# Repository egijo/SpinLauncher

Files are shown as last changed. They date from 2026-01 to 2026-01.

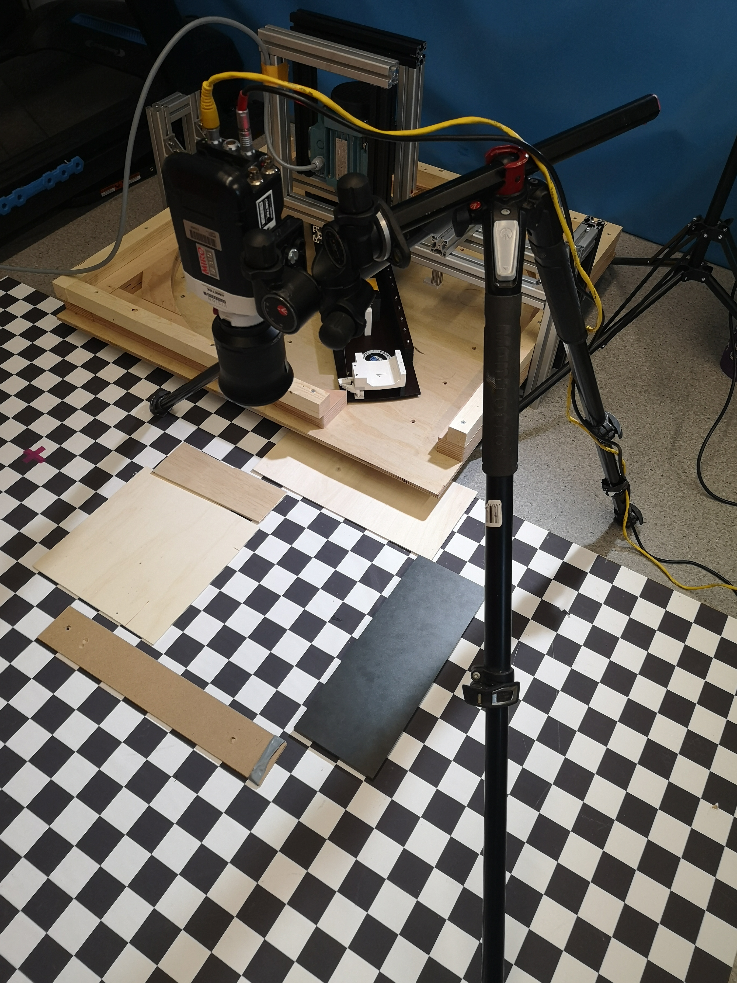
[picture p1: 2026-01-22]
pictures/Messsetup/V1/IMG_20260114_160319.jpg

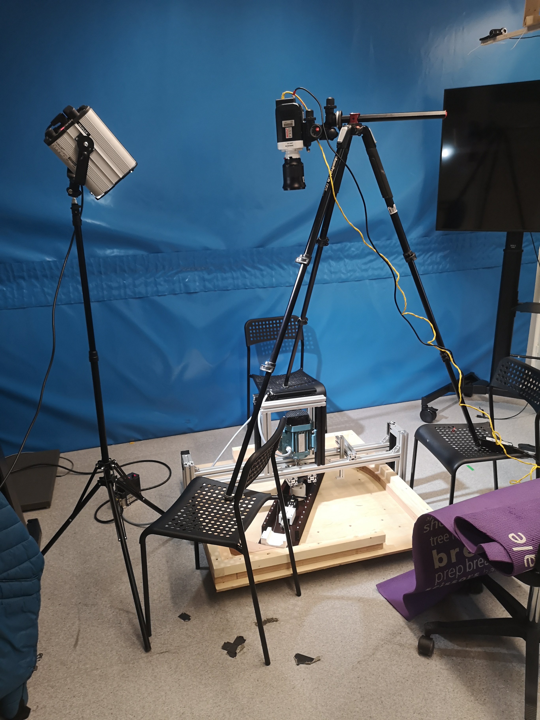
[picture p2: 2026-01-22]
pictures/Messsetup/V1/IMG_20260108_142438.jpg

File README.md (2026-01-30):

# SpinLauncher

## Project Group
- Mara Sandner
- Ruven Overberg
- Jonas Egitz

## Project Overview
The SpinLauncher is a mechanical puck launching system designed to accelerate an ice hockey puck using centrifugal force. A rotating arm generates controlled launch velocities, allowing different puck speeds to be set reproducibly. In addition to linear speed control, the system enables the generation of puck spin, which is relevant for realistic shot simulation.

The primary goal of the SpinLauncher is to produce repeatable and well-defined hockey shots. The system was developed as an extension and improvement of the shooting device used in the master’s thesis “Hockey Pro”, which aimed to generate reproducible shots for a camera-based ice hockey shooting training system.

The SpinLauncher project was carried out as a student project within the Master’s program (MST) during the Winter Semester 2025/2026.

## System Concept & Principle
The core mechanical concept of the SpinLauncher is a horizontally rotating arm driven by an electric motor. Two standard ice hockey pucks are mounted at opposite ends of the arm. This symmetric configuration ensures dynamic balance during rotation, significantly reducing vibrations and mechanical stress on the system.

During operation, both pucks are accelerated simultaneously and experience identical centrifugal forces. The system is designed for bidirectional release, meaning that the mechanical release principle is implemented on both sides of the rotating arm. In experimental operation, however, only one puck is used for measurement, while the second puck is safely intercepted. This approach preserves balance.

By adjusting the rotational speed of the arm, the launch velocity of the puck can be precisely controlled. The combination of symmetric mass distribution and controlled release enables reproducible shot conditions and stable system behavior.

## Hardware Setup
The SpinLauncher hardware consists of a mechanically simple but dynamically balanced rotating system. The central component is a rigid wooden arm with a total diameter of approximately 80 cm, mounted horizontally and driven by an electric asynchronous motor. The geometry and dimensions of the rotating arm are defined in the CAD model [`/drawings`](./drawings).

Two standard ice hockey pucks are mounted at opposite ends of the rotating arm. This symmetric mass distribution ensures dynamic balance during operation and significantly reduces vibrations at higher rotational speeds. Each puck is inserted into a release mechanism. It is designed to imediately release the puck when it is being triggered. The servo mounted on the rotor is connected to the trigger through a wire. If the servo moves, it will pull the trigger of the release mechanism. This will release the puck as an outcome and the puck will be pressed against the wall because of the centrifugal forces. The next time the rotor will pass the puck outlet, the puck will fly through the outlet. The puck holders and integrated release mechanisms are defined in
[`/releaseMechanism`](./releaseMechanism). and the corresponding part files in the same directory.

The electronic components required for motor control and sensor feedback are documented in the [`/Electronic`](Electronic) directory. This folder contains the complete circuit schematic, including the motor drive, power supply, and the Hall effect sensor used for rotational speed measurement.

The rotating arm is connected to the motor shaft via a torque coupling, which ensures reliable torque transmission while maintaining axial alignment. All rotating components are mounted on a rigid frame structure made out ot ITEMs that supports the motor and ensures a stable horizontal rotation axis. The frame design, including mounting points for the motor and safety elements, is defined in [`/drawings`](./drawings).

## Control & Software
The SpinLauncher is controlled via a software-based speed control system that enables precise and reproducible adjustment of the launcher’s rotational velocity. The rotational speed of the arm is measured in real time using a Hall effect sensor, which detects the rotation of the motor shaft and provides feedback in the form of pulses. From these pulses, the system continuously calculates the current rotational speed in revolutions per minute (RPM).

The measured RPM is used to monitor the acceleration process and to verify that the predefined target speed has been reached. This feedback mechanism allows reliable speed setting and ensures that launches are performed only under well-defined conditions.

All control-related code is located in the [`/SpinlaunchController`](SpinlaunchController) directory of this repository.

In addition to the embedded control logic, a web-based control interface is implemented directly on the controller. The system hosts a lightweight web server that allows the user to:
- set target RPM values,
- set of release angle
- monitor the current rotational speed,
- manually trigger the puck release.

The release can be initiated via the web interface once the system has reached the predefined target RPM and angular position. This ensures that the puck is released only when both speed and orientation conditions are satisfied, improving repeatability and experimental control.

The modular structure of the control software allows easy modification of speed thresholds, angular conditions, and trigger logic. This design enables future extensions, such as automated release criteria, closed-loop speed control, or integration of additional sensor feedback.

## Experimental Setup & Test Procedure

### Experimental Setup

All experiments were conducted using a controlled laboratory setup designed to ensure reproducible launch and measurement conditions. The SpinLauncher was placed on the floor, and all measurements were performed under identical mechanical, camera, and lighting conditions.

High-speed recordings were acquired using a visually triggered camera system operating in an image-based auto-trigger mode. Image sequences were recorded before and after puck launch to capture the complete release event. The camera was positioned perpendicular to the puck trajectory, facing a calibrated checkerboard plane.

The camera configuration was identical for all experiments and is summarized below:

- **Frame rate:** 3200 fps  
- **Exposure time (shutter speed):** 310 µs  
- **Sensor resolution:** 1280 × 800 pixels  
- **Bit depth:** 12 bit  
- **Lens:** Fixed-focus lens, focal length 25 mm  
- **Distance between camera lens and checkerboard plane:** 52.5 cm  
- **Trigger mode:** Image-based auto-triggering based on grayscale intensity changes  
- **Recording duration:** approx. 0.09 s pre-trigger and 0.55 s post-trigger  

Images of the complete experimental setup, including camera placement and launcher orientation, are provided in the [`/pictures`](./pictures) directory.

### Test Procedure

The SpinLauncher was tested at multiple predefined target velocities. For each target speed, the launcher was accelerated to the corresponding rotational speed before the puck release was manually triggered.

The following test conditions were investigated:

- **25 km/h (≈ 166 RPM):** 11 repetitions  
- **45 km/h (≈ 299 RPM):** 11 repetitions  
- **55 km/h (≈ 365 RPM):** 2 repetitions  

The number of repetitions at 55 km/h was limited due to **mechanical failure of the system**, which resulted in damage to the launcher and prevented further testing at this speed.

All measurement data, including raw results and processed values, are stored in the [`/Measurements/V2`](./Measurements/V2) directory. This folder contains:
- recorded measurement data,
- analysis scripts,
- and the corresponding Excel files that logged the test run. 

The software and data provided in this repository allow full traceability of the experimental procedure and results presented in the paper and presentation.

## Data & Analysis

The recorded measurement data were processed and analyzed to evaluate the launch velocity and repeatability of the SpinLauncher. All raw data and processed results are stored in the [`/Measurements/V2`](./Measurements/V2) directory.

Launch velocities were determined based on image sequences recorded with the high-speed camera. The puck position was extracted frame by frame using a **custom Python analysis script**, and the displacement over time was used to calculate the translational velocity after release. Only frames in which the puck had fully disengaged from the launcher were considered for evaluation.

High-speed video recordings were used to estimate the puck velocity over a planar checkerboard pattern. The camera was intrinsically calibrated using 23 checkerboard images (4×5 inner corners, 35×35mm square size), and the resulting calibration parameters were applied to undistort all videos. The puck was tracked frame-wise using a CSRT tracker, while the background checkerboard (5×5cm) provided a spatial reference for converting pixel coordinates to real-world distances. From the tracked positions, distance–time data were extracted, stored in CSV format, and used to compute velocities and generate distance–time and scatter plots.

For each target speed, multiple repetitions were analyzed to assess repeatability. Mean values and variations of the measured launch velocities were calculated and used to compare the achieved performance across different operating points. The resulting values form the basis for the plots and tables presented in the presentation and paper.

The Python scripts used for data processing is provided in the [`/Measurements/V2`](./Measurements/V2) directory. All analysis steps are documented and can be reproduced or extended by future users.

## Results Summary

The SpinLauncher demonstrated reliable and reproducible performance across the tested velocity range. For target speeds of **25 km/h** and **45 km/h**, the system achieved stable operation with consistent launch conditions over **11 repeated trials** each. The measured launch velocities showed low variation between repetitions, indicating good repeatability of the centrifugal acceleration and release mechanism.

At higher target speeds, the system approached its mechanical limits. Tests at **55 km/h** were successfully performed for **two repetitions**, confirming the feasibility of higher launch velocities in principle. However, subsequent testing at this speed was discontinued due to mechanical failure of the launcher, which resulted in damage to the system. This failure highlights the increasing structural and dynamic loads acting on the rotating components at elevated rotational speeds. In addition, the response time of the release mechanism was insufficient at higher rotational speeds, leading to delayed puck disengagement and contributing to the observed mechanical failure.

All raw and processed measurement data supporting these results are stored in the [`/Measurements/V2`](./Measurements/V2) directory. This folder contains the complete dataset used for analysis, including measurement files, evaluation scripts, and plots.

Overall, the results confirm that the SpinLauncher is well suited for generating reproducible puck launches within a moderate speed range. The experimental data further provide valuable insight into the mechanical limitations of the current design and define clear boundaries for safe and reliable operation.

## Limitations and Future Work

The current SpinLauncher design exhibits several limitations that became apparent during high-speed testing and provide clear directions for future improvements.

One key limitation is the performance of the release mechanism. At elevated rotational speeds, the response time of the current mechanism is insufficient, leading to delayed puck disengagement. Future work should focus on improving the release dynamics to ensure reliable operation at higher RPMs. In particular, the use of a linear pin actuator with sufficient pulling force should be considered as an alternative to the currently used servo-based solution.

Another limitation concerns the structural stiffness of the rotating arm. At higher rotational speeds, the arm exhibited noticeable deflection, causing parts of the rotating assembly to come into contact with surrounding components. This indicates that the arm stiffness is insufficient for operation at higher loads. Future iterations should therefore include structural reinforcement of the rotating arm or the use of stiffer materials.

A further limitation is the limited control and quantification of puck spin. While spin is generated implicitly by the launcher, it is neither independently adjustable nor directly measured. A potential approach to influence puck spin is to vary the launching angle, which may allow controlled manipulation of rotational behavior. In principle, the high-speed camera recordings acquired during the experiments provide sufficient data to extract and analyze puck spin. However, no dedicated analysis or systematic investigation of spin effects has been conducted so far.

Safety is another important aspect that requires improvement. In the current setup, the second puck mounted on the rotating arm remains in motion after the primary puck is released. As a concrete future improvement, the unused puck should be intercepted immediately at the launcher exit using a dedicated catching or deflection mechanism. This would significantly reduce the risk associated with uncontrolled puck motion and improve the overall safety of the system.

Addressing these limitations is expected to increase the maximum achievable launch speed while improving reliability, experimental control, and operational safety.

## Further Documentation
Paper:

Notion: https://www.notion.so/mci-medtech/Hockey-PRO-28091a52c19480998451c0e8b286c635

final Presentation: [`Presentation`](Documentation)

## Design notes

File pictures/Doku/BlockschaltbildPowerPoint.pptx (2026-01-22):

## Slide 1

Voltage Regulator

Battery

µC

Servo

Hall Effect Sensor

Webserver

Logic

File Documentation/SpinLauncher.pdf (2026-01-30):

1

# SpinLauncher

Jonas, Ruven, Mara

2

# Background & Project Goal

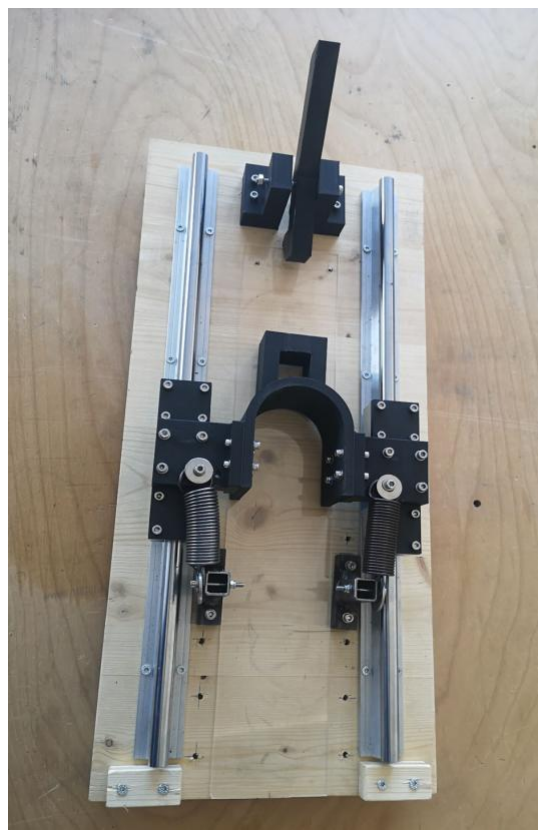
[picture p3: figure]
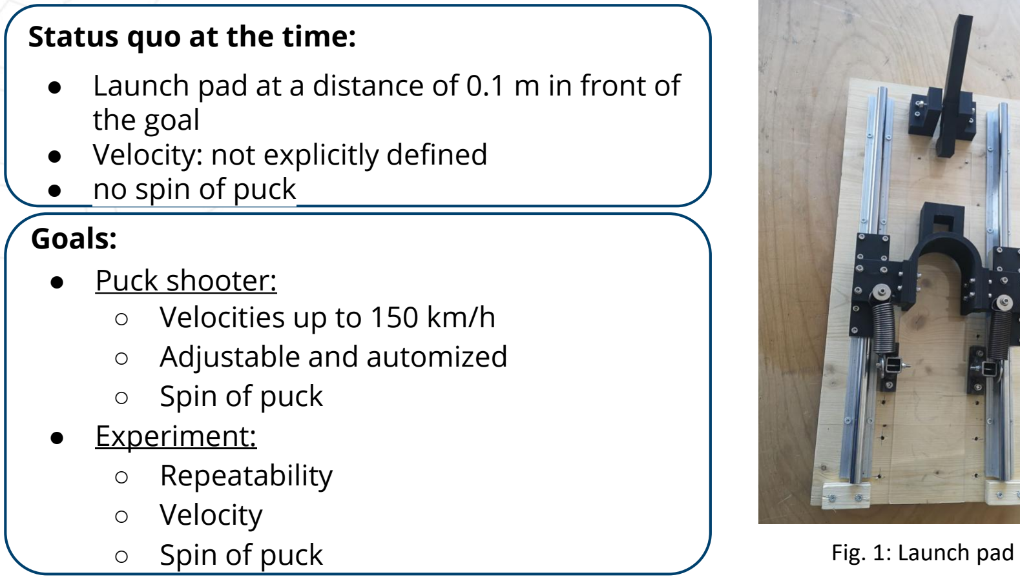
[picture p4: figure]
Status quo at the time:; the goal ● Velocity: not explicitly defined ● no spin of puck; Goals: ● Puck shooter: ○ Velocities up to 150 km/h ○ Adjustable and automized ○ Spin of puck ● Experiment: ○ Repeatability ○ Velocity; ○ Spin of puck; Fig. 1: Launch pad

- Launch pad at a distance of 0.1 m in front of

3

# Research Question

The aim of this project was to

### 1. develop a new launching system and 2. How consistent and stable is the hockey puck behaviour produced

by the new developed puck launching system (SpinLauncher), specifically regarding trajectory accuracy, velocity and spin?

4

# Decision Matrix

| Catapult | Spin Launch | Springs | 2-3 Wheels | Railgun | Free Fall - Gravity | 10 Wheels
Complexity | 5 | 4 | 4 | 5 | 10 | 1 | 7
Spin | 3 | 3 | 10 | 1 | 8 | 7 | 1
Velocity | 5 | 1 | 9 | 4 | 1 | 7 | 3
Size | 7 | 5 | 2 | 2 | 5 | 10 | 4
Complexity Release Mechanism | 2 | 4 | 2 | 1 | 3 | 1 | 1
Repeatability | 2 | 1 | 1 | 4 | 1 | 4 | 3
Feasibility | 6 | 3 | 2 | 3 | 10 | 2 | 4
Sum | 30 | 21 | 30 | 20 | 38 | 32 | 23

5

# SpinLauncher - Block diagram

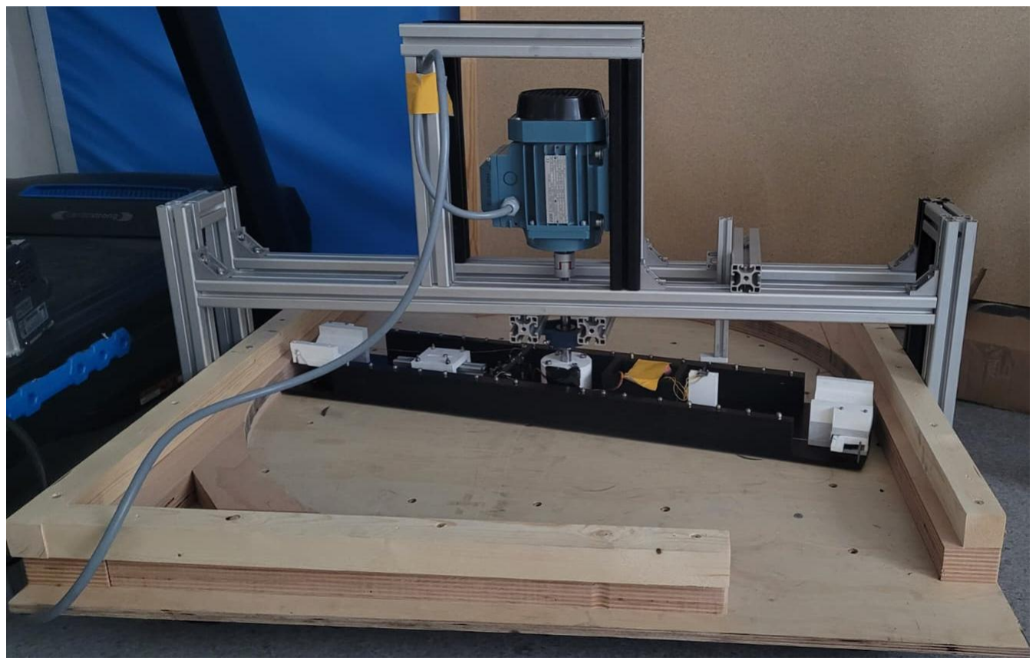
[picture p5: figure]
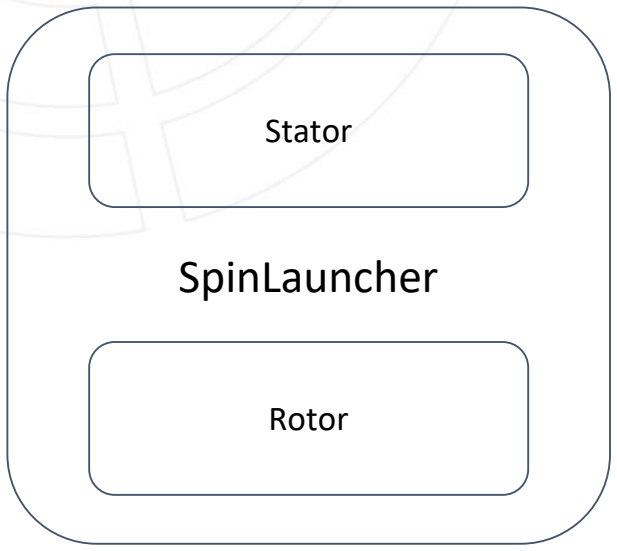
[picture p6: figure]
SpinLauncher; Stator; Rotor

Fig. 2: SpinLauncher block diagram | Fig. 3 : SpinLauncher

6

# - ITEM frame

# - wood boundaries

# - Bearings

# - 3 Phase asynchronous motor

# - 1 Phase AC frequency converter

# SpinLauncher - Stator

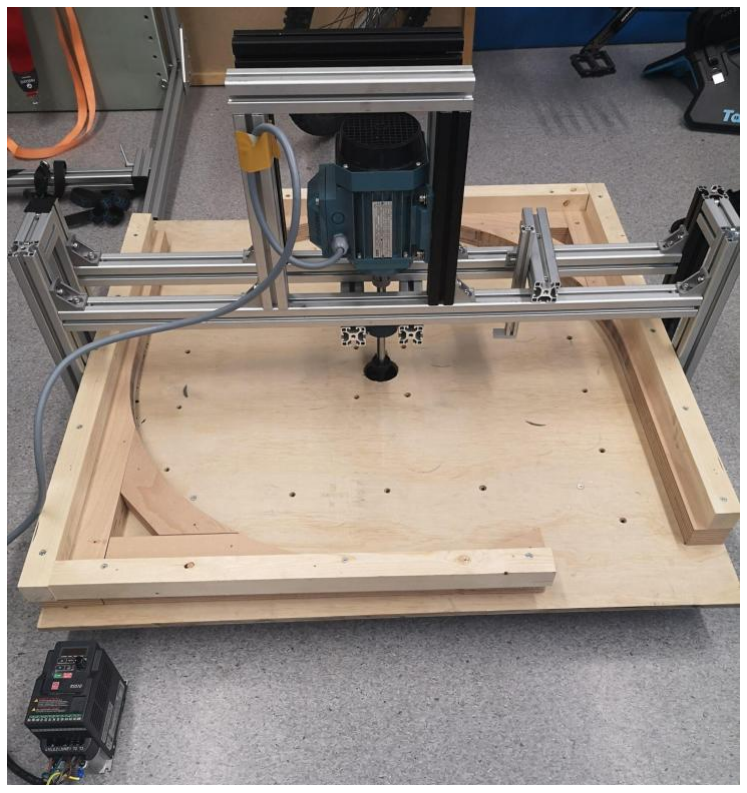
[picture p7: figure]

Fig. 4: SpinLauncher - Stator

7

## - wood construction

## - 2x release mechanism

## - Counterweight

## - Servo motor

- µC

## - Battery

## - Hall effect sensor

# SpinLauncher - Rotor

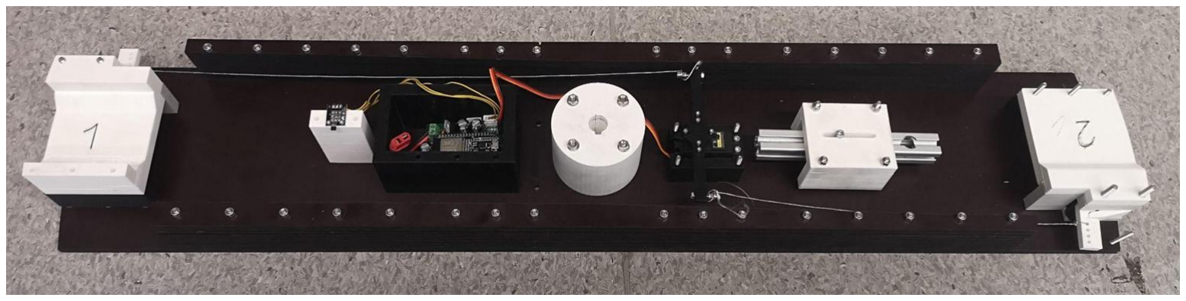
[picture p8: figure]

Fig. 5: SpinLauncher - Rotor

8

# Electronic Block Diagram

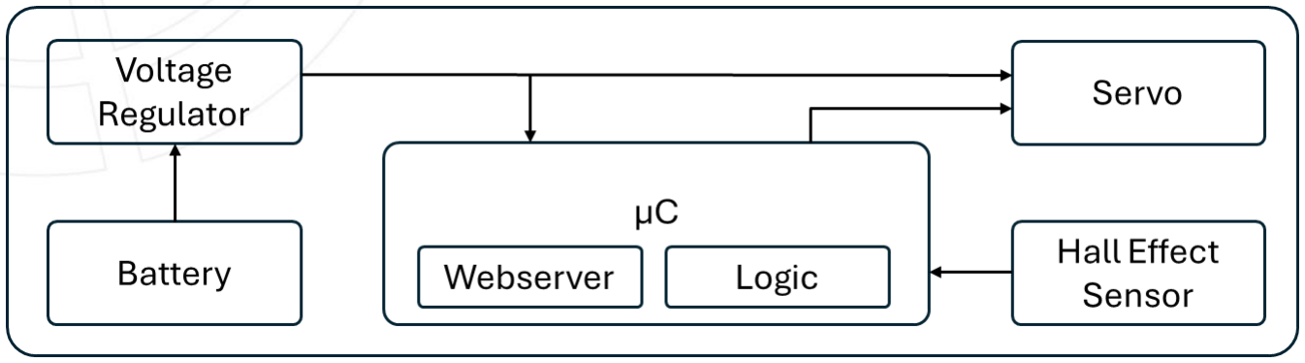
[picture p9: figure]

Fig. 6: Block diagram of electronic on Rotor

# Release Mechanism Design

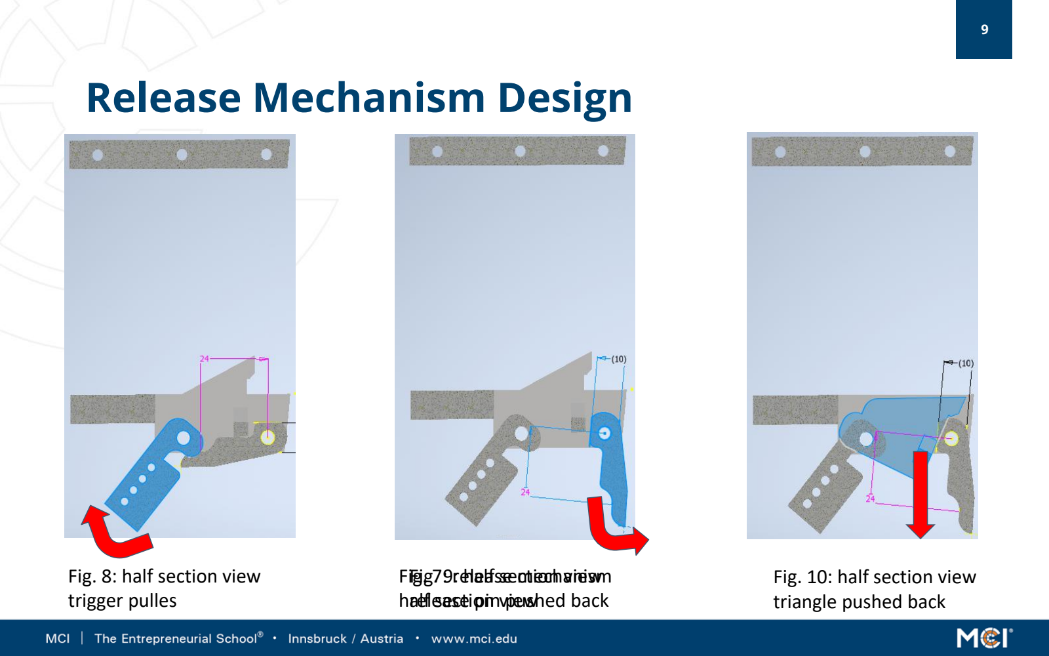
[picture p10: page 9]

9

Fig. 7: release mechanism
half section view

Fig. 8: half section view
trigger pulles

Fig. 9: half section view
release pin pushed back

Fig. 10: half section view triangle pushed back

# Experimental Setup Schematic

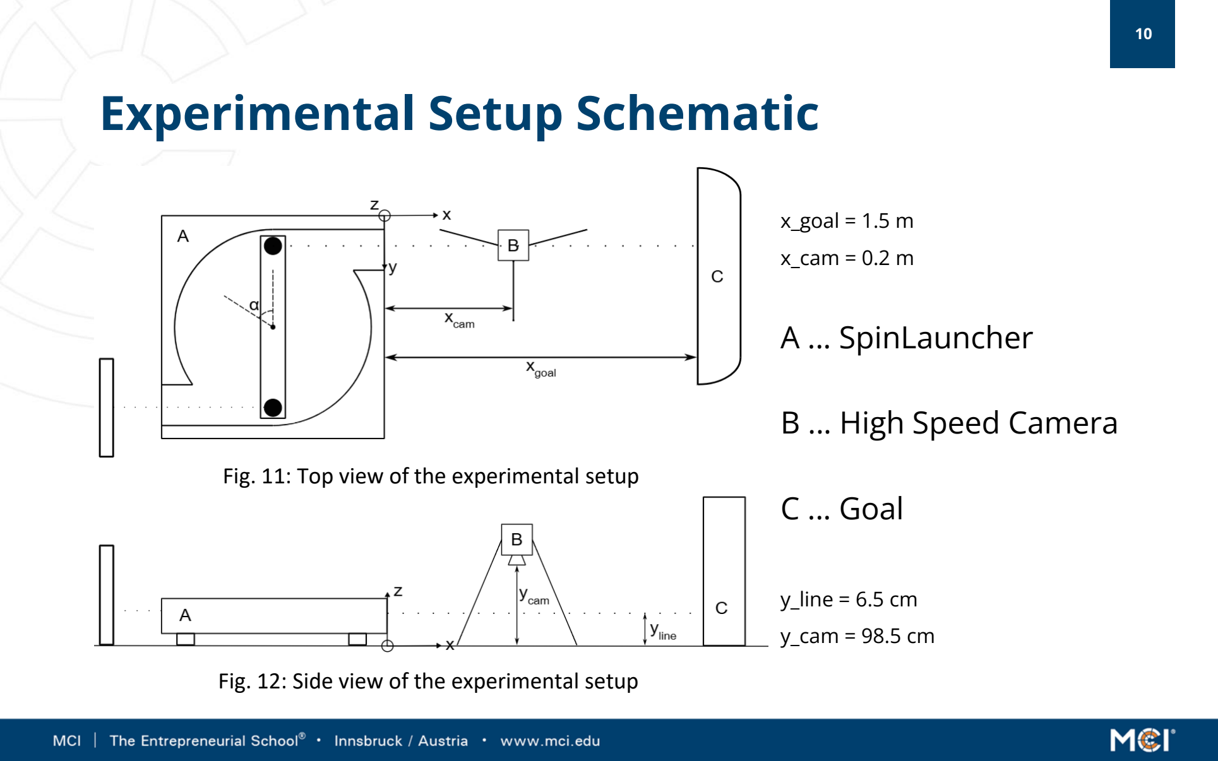
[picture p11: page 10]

10

x_goal = 1.5 m
x_cam = 0.2 m

# A … SpinLauncher

# B … High Speed Camera

# C … Goal

y_line = 6.5 cm
y_cam = 98.5 cm

Fig. 11: Top view of the experimental setup

Fig. 12: Side view of the experimental setup

11

# Experimental Setup

### Analysis focused on initial puck motion after release

## SpinLauncher

### High-speed camera

### Illumination

### Horizontal puck launch direction

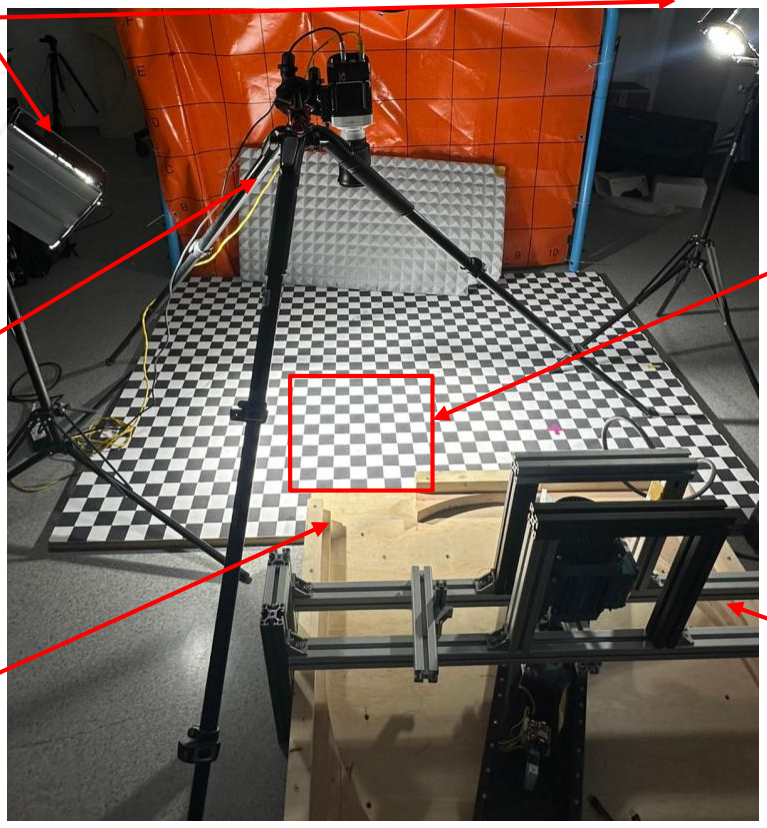
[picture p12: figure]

Fig. 13: Experimental Setup

12

## - Bit depth: 12

## - Resolution: 1280 x 800

## - Sample rate: 3200 fps

## - Exposure time 310 µs

## - Focus: manual

## - Trigger: - Image-Based Auto-Trigger - placed at outlet of SpinLauncher

# High Speed Camera Settings

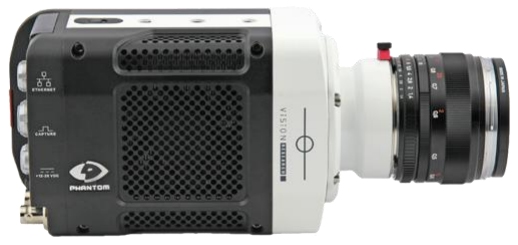
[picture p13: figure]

Fig. 14: PHANTOM MIRO M310

13

### - Repetitions: 11 - Settings:

# Experimental Parameters

Velocity | 25 km/h | 45 km/h | 55 km/h | 65 km/h
RPM - ideal | 166 | 299 | 365 | 431
RPM - real | 167 | 298 | 369 | -
Launch angle | 20° | 0° | 0° | 0°

### The device broke down after the third run at 55 km/h. → no further tests

# Test Run

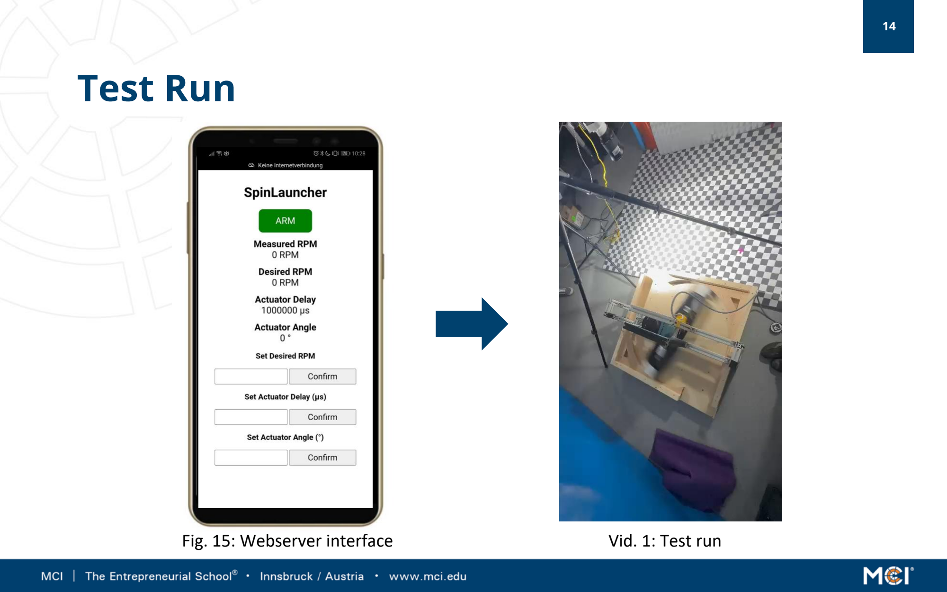
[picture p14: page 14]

14

Fig. 15: Webserver interface | Vid. 1: Test run

15

# Experiment SlowMo Demo

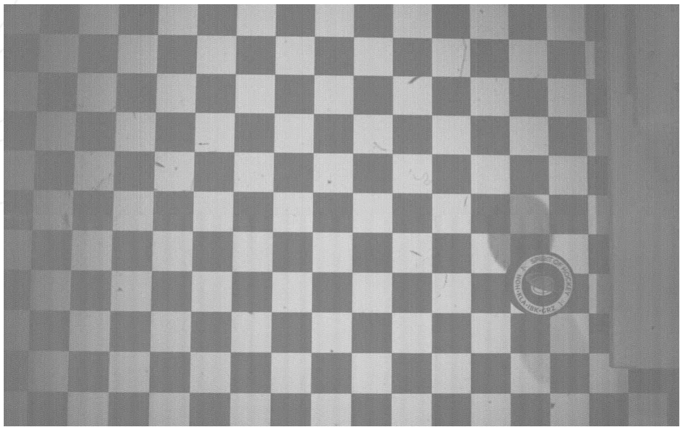
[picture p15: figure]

Vid. 2: Slow motion demo flight of puck (25km/h)

16

# Data Processing

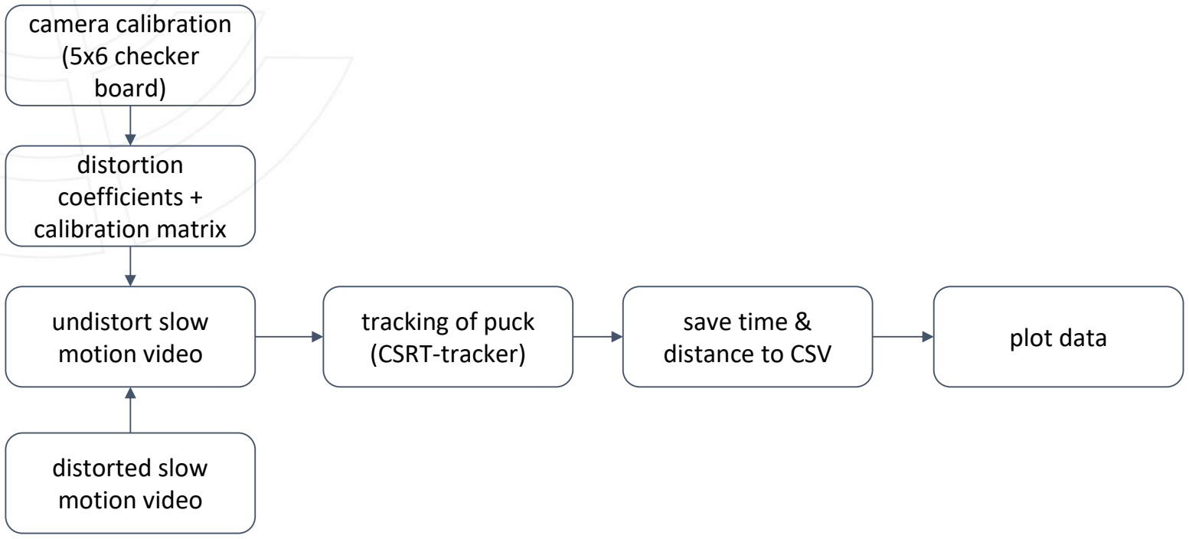
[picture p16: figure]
distorted slow motion video; camera calibration (5x6 checker board); distortion coefficients + calibration matrix; undistort slow motion video; tracking of puck (CSRT-tracker); save time &; distance to CSV; plot data

Fig. 16: Flowchart of data processing

17

# Results: 25 km/h

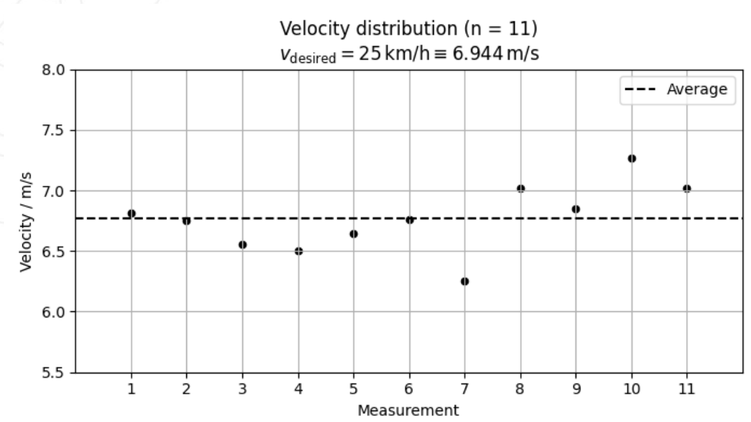
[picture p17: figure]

Fig. 17: Scatter plot of velocity distribution for 25 km/h target velocity

### Mean value: - 24.36 km/h

### Standard deviation: - 1.00 km/h

18

# Results: 45 km/h

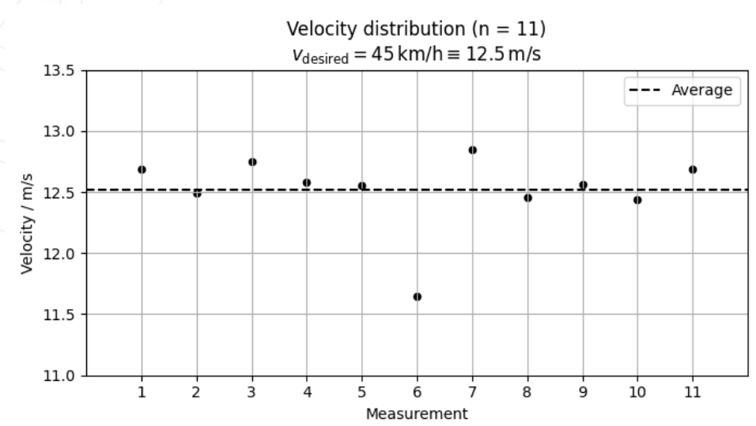
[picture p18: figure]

Fig. 18: Scatter plot of velocity distribution for 45 km/h target velocity

### Mean value: - 45.07 km/h

### Standard deviation: - 1.14 km/h

19

# Results: 55 km/h

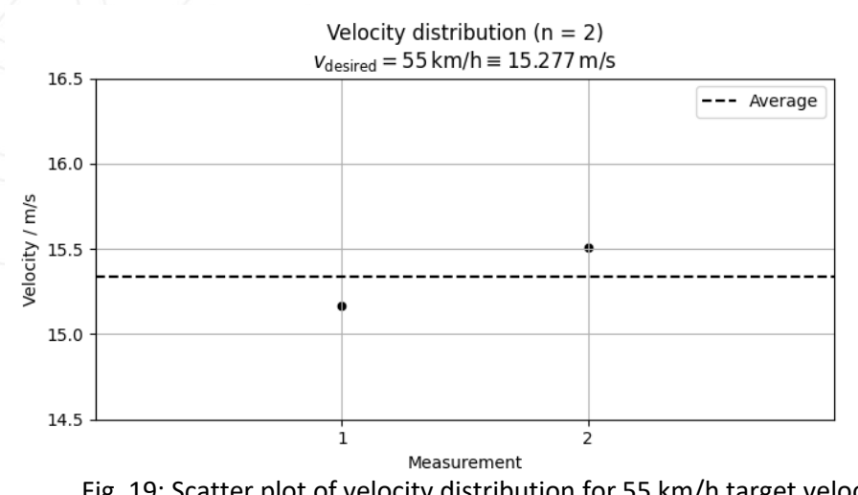
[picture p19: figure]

Only two valid measurements
→ No statistical evaluation possible, but it is still visible that the speed is approx. 55 km/h

Fig. 19: Scatter plot of velocity distribution for 55 km/h target velocity

### Mean value: - 55.22 km/h

### Standard deviation: - 0.86 km/h

20

# Results: distance-time-diagram

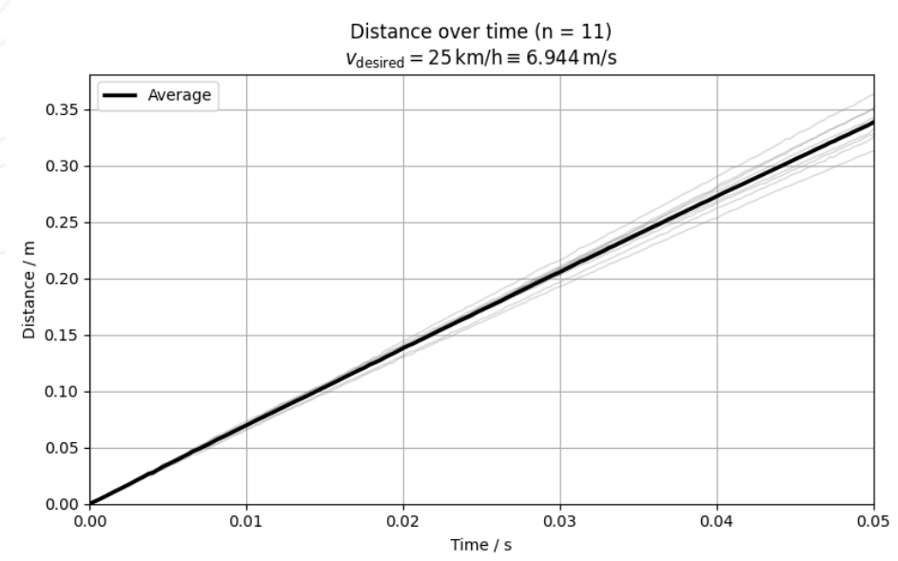
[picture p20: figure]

Fig. 20: Distance-time-plot for 25 km/h target velocity

21

# - Manufacturing tolerances

# - Release Mechanism

## - Cable pull

## - Flex of material - Servo actuation time

# - communication FC and µC

# - Tight schedule

# Limitations and future work

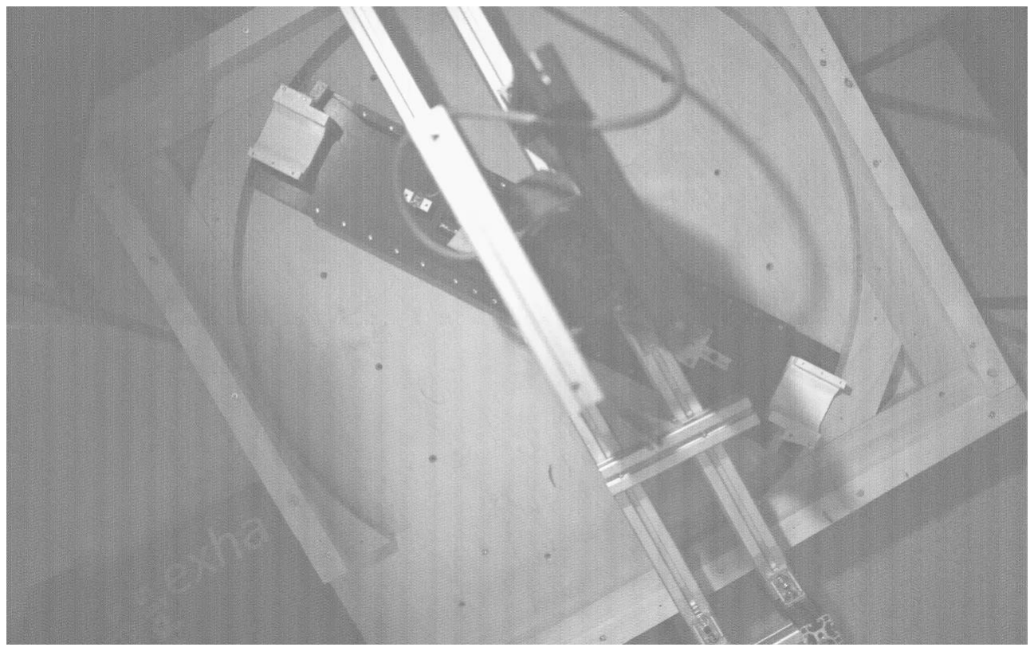
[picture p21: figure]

Vid. 3: Limitation of the cable pull

22

## Goals:

### - Puck shooter:

# Conclusion

Velocities up to 150 km/h | no → 55 km/h
Configurable and automized | yes
Spin | yes
Velocity repeatable | yes
Spin repeatable | unknown

### - Experiment:

### - majority of goals achieved - higher speed than before - improvement of Release Mechanism

23

# Thank you for your Attention!

Jonas, Ruven, Mara

24

# - Github: https://github.com/egijo/SpinLauncher

# - Notion: https://www.notion.so/mci-medtech/Hockey-PRO-

28091a52c19480998451c0e8b286c635 (https://www.notion.so/mci-medtech/Hockey-PRO-28091a52c19480998451c0e8b286c635)

# Documentation

25

Posch, M., Hockey PRO – Development of a Camera-Based Ice Hockey Shooting Training System, Master’s Thesis, Management Center Innsbruck, 2024.

# Literature

26

# Electronic Schematic

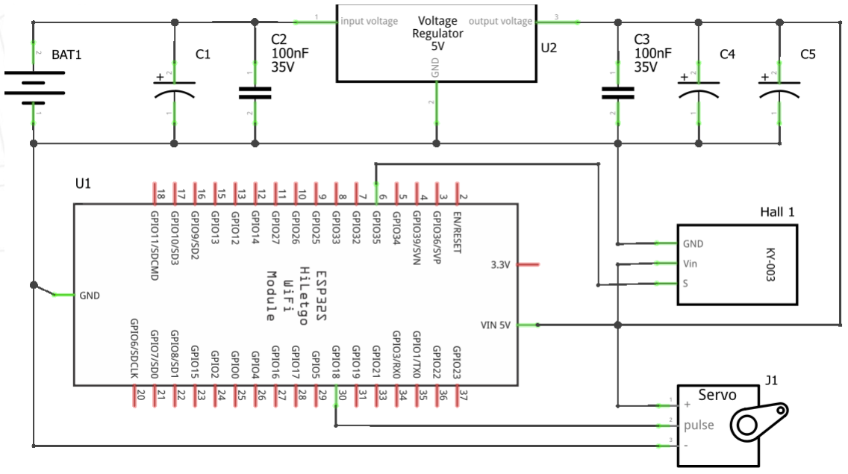
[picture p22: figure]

Fig. 20: Schematic of rotor electronic

27

# 3 Phase Motor Type Plate

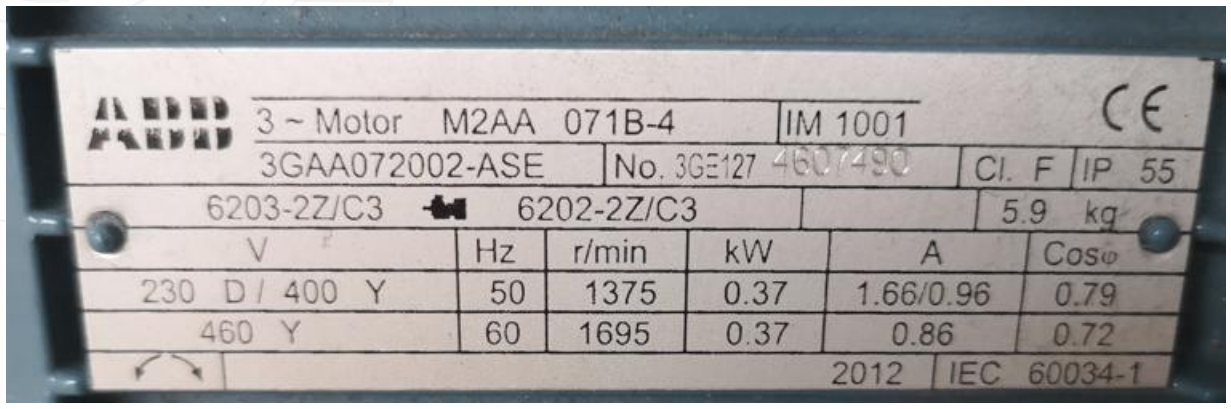
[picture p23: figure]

Fig. 21: Motor type plate

28

# Frequency Converter Type Plate

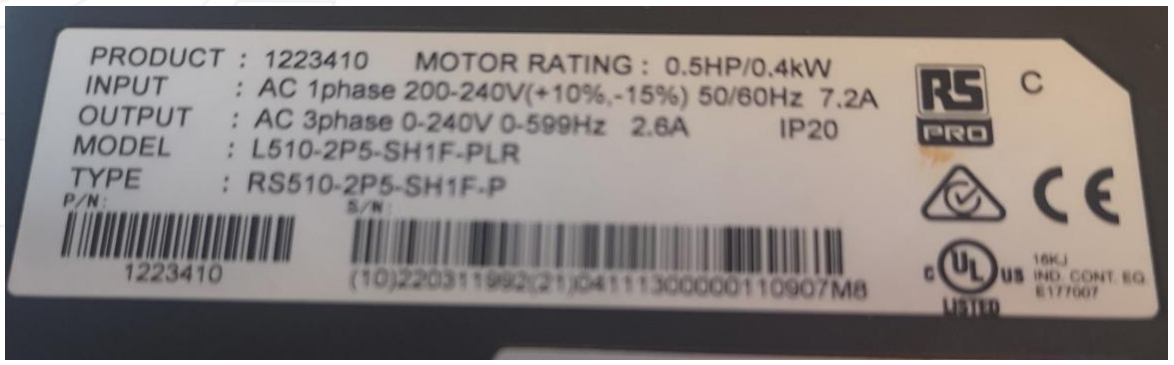
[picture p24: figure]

Fig. 22: Frequency converter type plate

# Results: distance-time-diagram 45 km/h

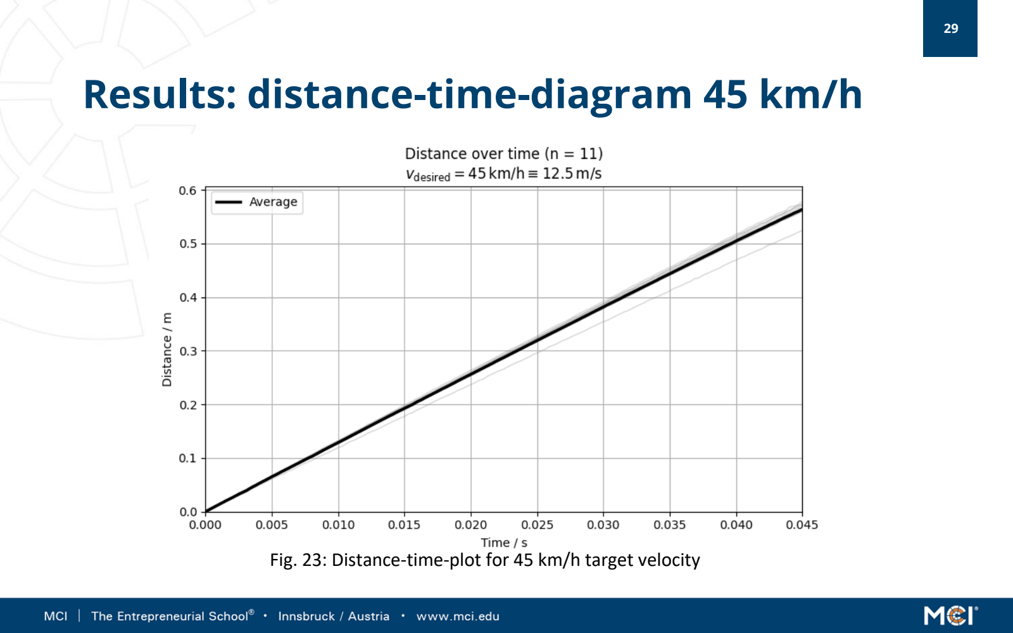
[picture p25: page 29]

29

Fig. 23: Distance-time-plot for 45 km/h target velocity

30

# Results: distance-time-diagram 55 km/h

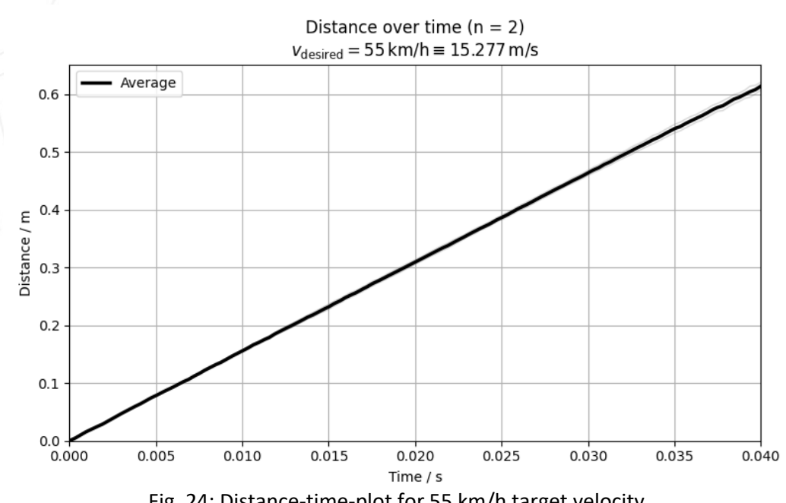
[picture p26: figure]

Fig. 24: Distance-time-plot for 55 km/h target velocity

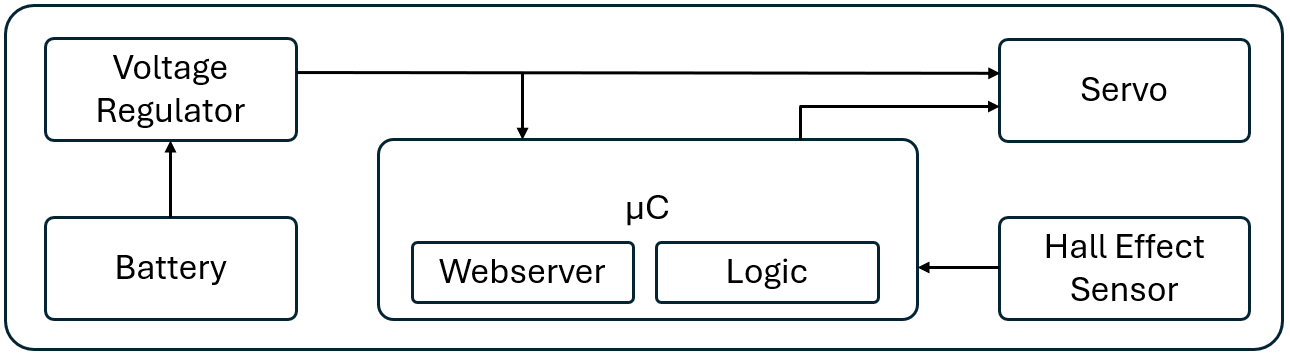
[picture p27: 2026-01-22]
pictures/Doku/SchematicBlockschaltbildPaper.png

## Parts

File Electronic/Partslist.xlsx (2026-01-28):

ID | Name | Description | Amount
BAT1 | Battery | Top Fuel 900 LIPO, 900 mAh, 3S / 11,1V, 10,0Wh, 25C | 1
U1 | Micro Controller | ESP32 WROOM | 1
U2 | Voltage Regulator | Lineare Spannungsregler 5.0V 1.5A Positive | 1
Hall1 | Hall Effect Sensor | KY-003 | 1
J1 | Servo Motor | MG996R | 1
C1 | Electrolytic Capacitor | 1000µF | 1
C2 | Capacitor | 100nF | 1
C3 | Capacitor | 22nF | 1
C4 | Electrolytic Capacitor | 1000µF | 1
C5 | Electrolytic Capacitor | 1000µF | 1

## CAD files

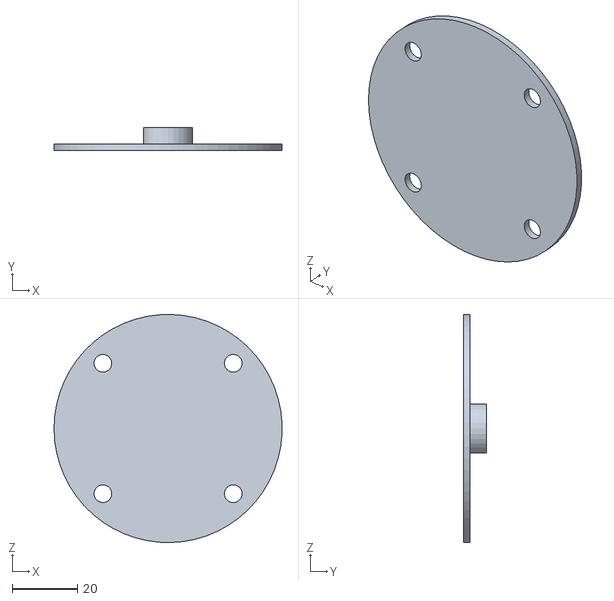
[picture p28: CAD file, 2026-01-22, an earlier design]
drawingsV2/FlanschSchablone.stl
70.0 x 7.00 x 70.0

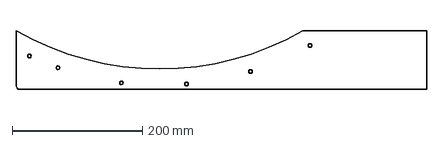
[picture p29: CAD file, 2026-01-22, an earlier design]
drawingsV2/schablone2.dxf
630.0 x 90.0 mm

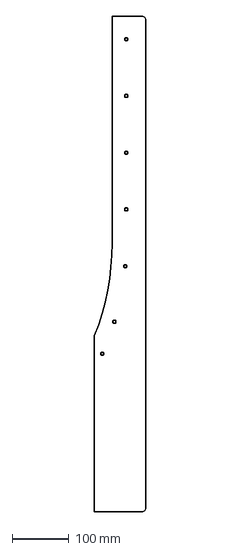
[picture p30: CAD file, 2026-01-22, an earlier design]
drawingsV2/schablone1.dxf
90.0 x 872.3 mm

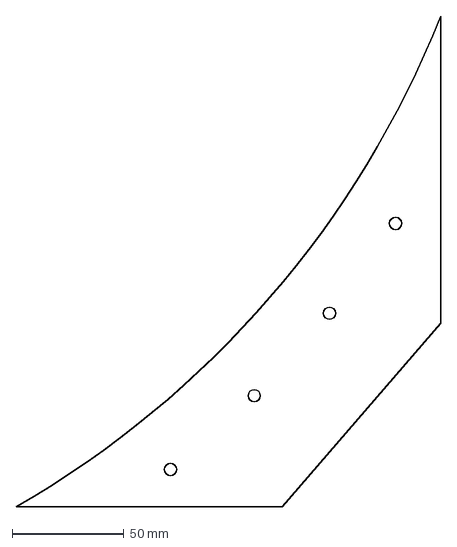
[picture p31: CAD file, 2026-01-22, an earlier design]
drawingsV2/schablone3.dxf
190.0 x 219.6 mm

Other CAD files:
drawings/BoundaryV1.ipt
drawings/BoundaryV1splitV1.ipt
drawings/BoundaryV2.ipt
drawings/ESP box.ipt
drawings/Flansch 3Ddruck.ipt
drawings/FlanschKugellager12mm/7508851.iam
drawings/FlanschKugellager12mm/7508851_01.ipt
drawings/FlanschKugellager12mm/7508851_02.ipt
drawings/FlanschKugellager15mm/7508860.iam
drawings/FlanschKugellager15mm/7508860_01.ipt
drawings/FlanschKugellager15mm/7508860_02.ipt
drawings/FlanschV1.ipt
drawings/Item2020VerticalMagnetHolderV1.ipt
drawings/Item4040BearingHolder.ipt
drawings/Item4040MotorHorizontalV1.ipt
drawings/Item4040MotorVerticalV1.ipt
drawings/Item4040PlateHolderV1.ipt
drawings/Item4040RotorHorizontalStabilityV1.ipt
drawings/Item4040RotorHorizontalV1.ipt
drawings/Item4040RotorVerticalStabilityHolderV1.ipt
drawings/Item4040RotorVerticalV1.ipt
drawings/MVPV1.iam
drawings/MVPV2.iam
drawings/MotorV1.ipt
drawings/MotorV2.ipt
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

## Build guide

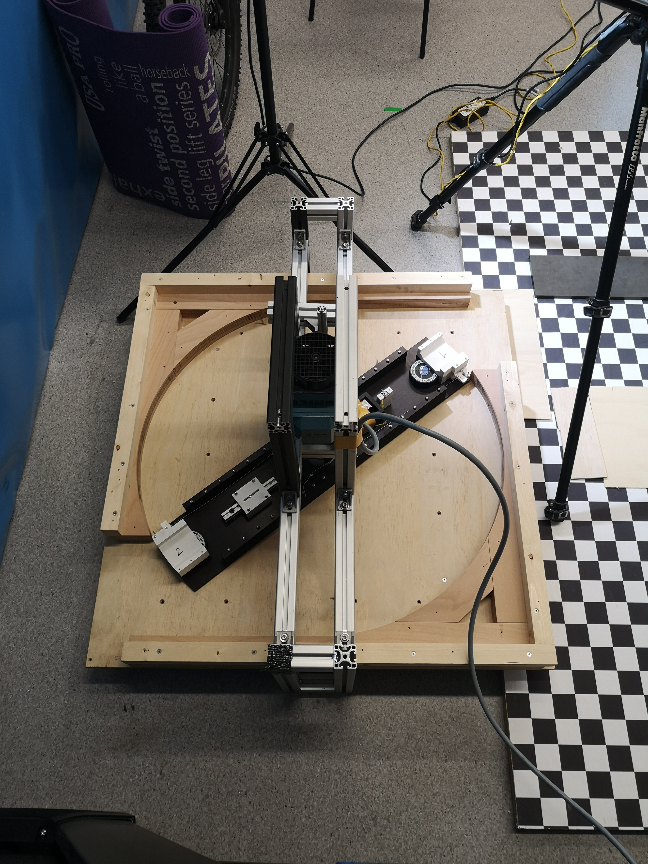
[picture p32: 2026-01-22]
pictures/Messsetup/V1/IMG_20260114_160340.jpg

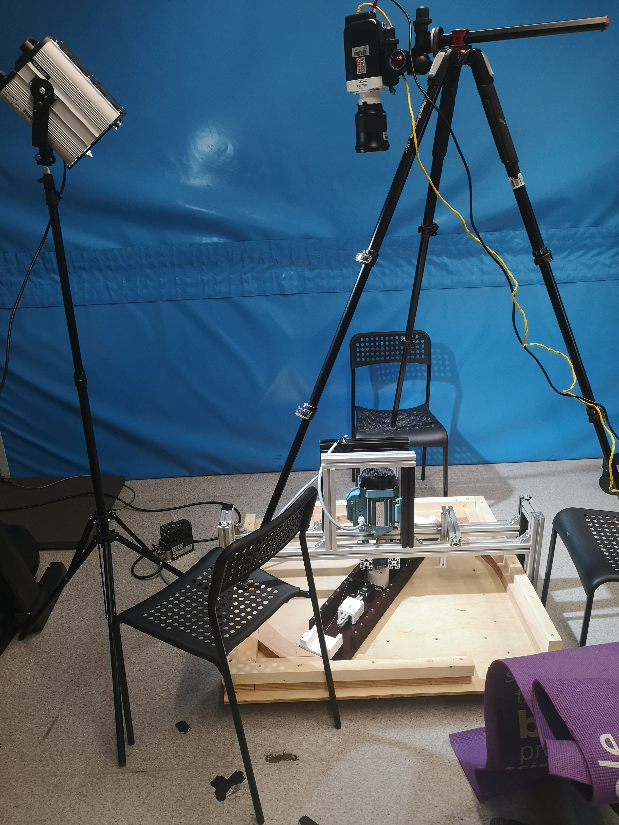
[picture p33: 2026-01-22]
pictures/Messsetup/V1/IMG_20260108_142441.jpg

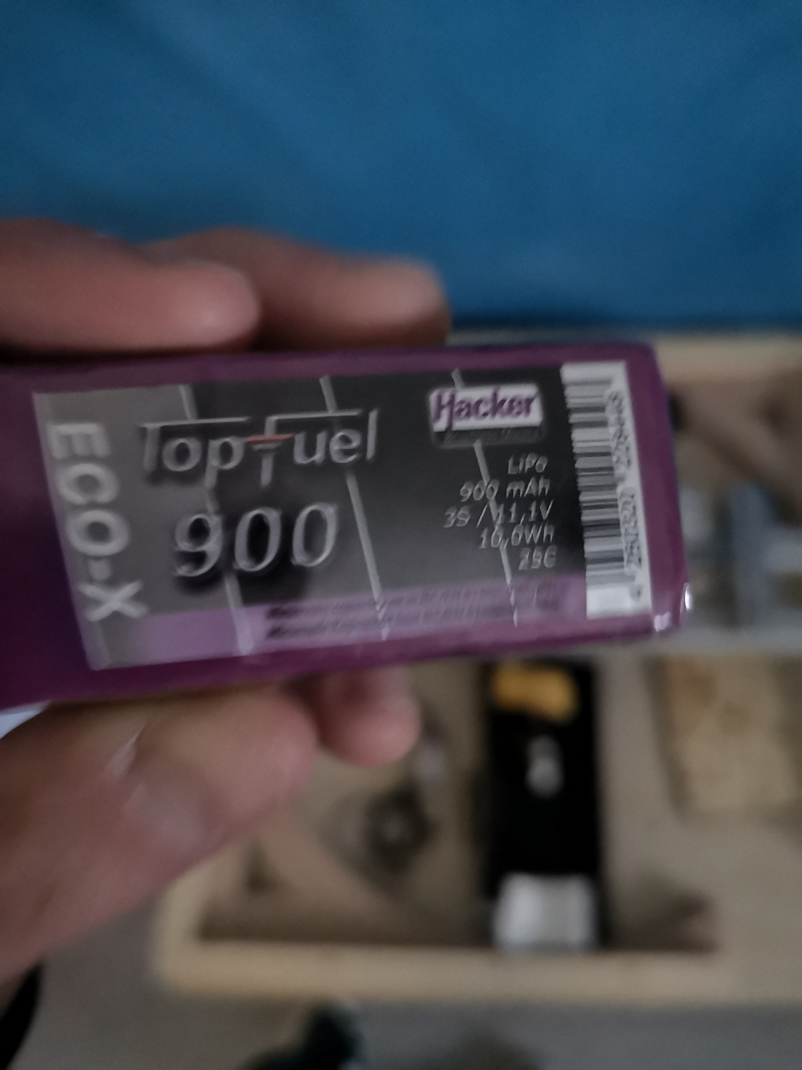
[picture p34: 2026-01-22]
pictures/Messsetup/V1/IMG_20260109_085259.jpg

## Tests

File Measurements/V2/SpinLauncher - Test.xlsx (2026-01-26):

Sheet: V1
 |  | Geschwindigkeit [km/h]
 |  | 25 | 40 |  | 55
Wiederholung | Winkel [°] | 40 | 60 | 40 | 60 | 40
1 | - |  | ab Wiederholung 2: 30° |  | 20°: Abfäschung durch Bande
2 |  |  | ab Wiederholung 3: 25° |  | ab jetzt 350°
3 |  |  | ab Wiederholung 4: 20°
4
5
6
7
Geschwindigkeit [km/h] | 25 | 40 | 55
RPM - ideal | 165.8704883 | 265.3927813 | 365
RPM - real | 169 | 269 | 364
 | SpinLaunch |  | Objektiv
Abstand:
Board | 6.5 cm |  | 52.5 cm

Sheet: 20.01
20° Auslöse-Winkel
11x Wiederholungen
Geschwindigkeit [km/h] | 25 | 45 | 55
RPM - ideal | 165.8704883 | 298.566879 | 365
RPM - real | 167 | 298 | 369
 |  | Wiederholung 4: 10° | nur zwei Wiederholungen, da Spinlauncher kaputt
 |  | ab Wiederholung 5: 0°
Abstand: | SpinLaunch |  | Objektiv
Board | 6.50 |  | 98.5

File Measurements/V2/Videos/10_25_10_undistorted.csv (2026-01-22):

frame | time_s | x_px | y_px | distance_m
1 | 0.0 | 1046 | 531 | 0.0
2 | 0.0003125 | 1043 | 533 | 0.0023626818049387465
3 | 0.000625 | 1041 | 532 | 0.0033413366521165186
4 | 0.0009375 | 1039 | 532 | 0.004633600241458958
5 | 0.00125 | 1035 | 532 | 0.007237914956827165
6 | 0.0015625 | 1033 | 531 | 0.008518770395312458
7 | 0.001875 | 1029 | 533 | 0.011216758534363673
8 | 0.0021875 | 1025 | 532 | 0.0137766839474241
9 | 0.0025 | 1023 | 532 | 0.01508590940895093
10 | 0.0028125 | 1018 | 531 | 0.018348120851442218
11 | 0.003125 | 1016 | 531 | 0.01965870091225952
12 | 0.0034375 | 1013 | 531 | 0.02162457100348547
13 | 0.00375 | 1011 | 531 | 0.022935151064302772
14 | 0.0040625 | 1009 | 531 | 0.024245731125120074
15 | 0.004375 | 1005 | 531 | 0.026866891246754676
16 | 0.0046875 | 1003 | 531 | 0.028177471307571977
17 | 0.005 | 999 | 532 | 0.030805601810970428
18 | 0.0053125 | 997 | 531 | 0.03210921149002388
19 | 0.005625 | 993 | 530 | 0.0347365530429812
20 | 0.0059375 | 991 | 531 | 0.036040951672475785
21 | 0.00625 | 986 | 531 | 0.03931740182451904
22 | 0.0065625 | 983 | 531 | 0.04128327191574499
23 | 0.006875 | 980 | 531 | 0.04324914200697094
24 | 0.0071875 | 976 | 531 | 0.045870302128605545
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

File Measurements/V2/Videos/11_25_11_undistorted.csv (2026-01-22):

frame | time_s | x_px | y_px | distance_m
1 | 0.0 | 1021 | 525 | 0.0
2 | 0.0003125 | 1019 | 526 | 0.0014947638643925953
3 | 0.000625 | 1016 | 526 | 0.003408586049013315
4 | 0.0009375 | 1012 | 525 | 0.006016308499965817
5 | 0.00125 | 1008 | 526 | 0.008715896187426287
6 | 0.0015625 | 1004 | 525 | 0.01136413827771321
7 | 0.001875 | 1002 | 526 | 0.01271867510180511
8 | 0.0021875 | 997 | 526 | 0.01605740993398108
9 | 0.0025 | 995 | 525 | 0.017380446777679026
10 | 0.0028125 | 990 | 526 | 0.020733619500235445
11 | 0.003125 | 987 | 526 | 0.022738104999801657
12 | 0.0034375 | 984 | 527 | 0.024769820351118837
13 | 0.00375 | 979 | 528 | 0.028147637930210266
14 | 0.0040625 | 978 | 527 | 0.028775660291553932
15 | 0.004375 | 974 | 526 | 0.031425610615386575
16 | 0.0046875 | 971 | 527 | 0.033450664572698366
17 | 0.005 | 966 | 528 | 0.03682098281478007
18 | 0.0053125 | 964 | 527 | 0.038126735345387255
19 | 0.005625 | 959 | 526 | 0.04145107138441656
20 | 0.0059375 | 957 | 527 | 0.04280352308444932
21 | 0.00625 | 954 | 526 | 0.04479306275801989
22 | 0.0065625 | 949 | 526 | 0.04813510998922469
23 | 0.006875 | 945 | 525 | 0.05080438288860023
24 | 0.0071875 | 942 | 525 | 0.0528098190552555
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

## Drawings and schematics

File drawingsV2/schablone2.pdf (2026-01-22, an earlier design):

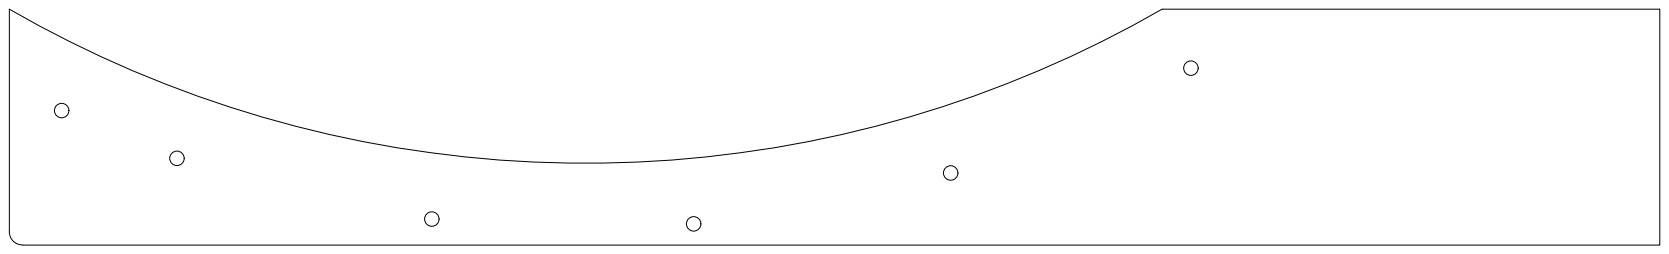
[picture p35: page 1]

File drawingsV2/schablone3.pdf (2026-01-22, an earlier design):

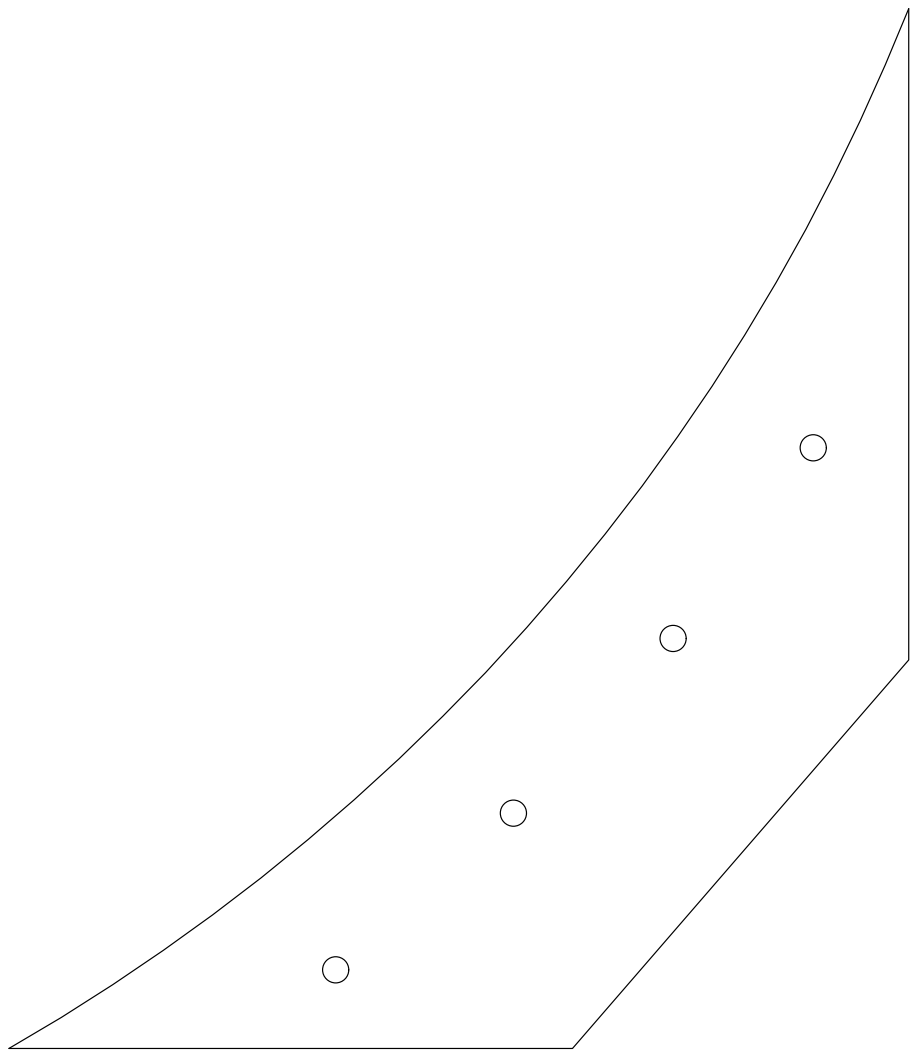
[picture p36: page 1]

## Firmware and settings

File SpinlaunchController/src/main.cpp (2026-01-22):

#include <WiFi.h>
#include <WebServer.h>
#include "driver/mcpwm.h"
#include "esp_system.h"

// =====================================================
// WLAN
// =====================================================
const char* ssid = "SpinLauncher";
const char* password = "12345678";
WebServer server(80);

// =====================================================
// Pins
// =====================================================
const int PIN_HALL  = 35;
const int PIN_SERVO = 18;

// =====================================================
// Servo Pulse (µs)
// =====================================================
const int SERVO_HOME = 1279;
const int SERVO_FIRE = 1130;

// =====================================================
// Timing
// =====================================================
volatile unsigned long actuatorDelayUs = 1000000;
const unsigned long RETURN_DELAY_US    = 5000000;
volatile float actuatorAngleDeg = 0.0;

// =====================================================
// Status / Flags
// =====================================================
volatile bool armEnabled        = false;
volatile bool timerStartedISR   = false;
volatile bool servoFiredISR     = false;

volatile unsigned long lastHallTime = 0;
volatile unsigned long deltaTime    = 0;
volatile bool newHallPulse          = false;

bool servoFired = false;
unsigned long servoFireTimestamp = 0;

// =====================================================
// RPM
// =====================================================
int measuredRPM = 0;
int desiredRPM  = 0;
int tolRPM      = 5;

// =====================================================
// Hardware Timer
// =====================================================
hw_timer_t* fireTimer = nullptr;

void updateActuatorDelay() {
  if (measuredRPM <= 0) return;

  unsigned long revolutionTimeUs = 60000000UL / measuredRPM;
  actuatorDelayUs = (unsigned long)((actuatorAngleDeg / 360.0f) * revolutionTimeUs);
}

// =====================================================
// ===================== ISR ============================
// =====================================================

// Hall sensor
void IRAM_ATTR ISR_Hall() {
  unsigned long now = micros();
  deltaTime = now - lastHallTime;
  lastHallTime = now;
  newHallPulse = true;

  if (armEnabled && !timerStartedISR &&
      measuredRPM >= (desiredRPM - tolRPM) &&
      measuredRPM <= (desiredRPM + tolRPM)) {

    timerStartedISR = true;
    armEnabled = false;

    timerWrite(fireTimer, 0);
    timerAlarmWrite(fireTimer, actuatorDelayUs, false);
    timerAlarmEnable(fireTimer);
  }
}

// fire
void IRAM_ATTR ISR_FireTimer() {
  mcpwm_set_duty_in_us(MCPWM_UNIT_0, MCPWM_TIMER_0, MCPWM_OPR_A, SERVO_FIRE);
  servoFiredISR = true;
}

// =====================================================
// HTML
// =====================================================
String getHTML() {
  return R"rawliteral(
<!DOCTYPE html>
<html>
<head>
<meta charset="utf-8">
<title>SpinLauncher</title>
<style>
body { font-family: Arial; text-align:center; margin-top:40px; }
.btn { font-size:22px; padding:15px 40px; color:white; border:none; border-radius:10px; }
.box { font-size:22px; margin:15px; }
input { font-size:20px; padding:5px; width:160px; text-align:center; }
</style>

<script>
async function update() {
  const r = await fetch('/data');
  const d = await r.json();

  document.getElementById('measured').innerText = d.measuredRPM + ' RPM';
  document.getElementById('desired').innerText  = d.desiredRPM  + ' RPM';
  document.getElementById('delay').innerText    = d.delay + ' µs';
  document.getElementById('angle').innerText    = d.angle + ' °';

  const btn = document.getElementById('armBtn');
  btn.innerText = d.arm ? "DISARM" : "ARM";
  btn.style.backgroundColor = d.arm ? "red" : "green";
}
setInterval(update, 300);
</script>
</head>

<body>
<h1>SpinLauncher</h1>

<button id="armBtn" class="btn" onclick="location.href='/arm'">ARM</button>

<div class="box"><b>Measured RPM</b><div id="measured">0 RPM</div></div>
<div class="box"><b>Desired RPM</b><div id="desired">0 RPM</div></div>
<div class="box"><b>Actuator Delay</b><div id="delay">0 µs</div></div>
<div class="box"><b>Actuator Angle</b><div id="angle">0 °</div></div>

<h3>Set Desired RPM</h3>
<form action="/setRPM">
<input type="number" name="value">
<input type="submit" value="Confirm">
</form>

<h3>Set Actuator Delay (µs)</h3>
<form action="/setDelay">
<input type="number" name="value">
<input type="submit" value="Confirm">
</form>

<h3>Set Actuator Angle (°)</h3>
<form action="/setAngle">
<input type="number" step="0.1" name="value">
<input type="submit" value="Confirm">
</form>

</body>
</html>
)rawliteral";
}

// =====================================================
// HTTP Handler
// =====================================================
void handleRoot() {
  server.send(200, "text/html", getHTML());
}

void handleArm() {
  armEnabled = !armEnabled;
  timerStartedISR = false;
  server.sendHeader("Location", "/");
  server.send(303, "text/plain", "");
}

void handleSetRPM() {
  if (server.hasArg("value")) desiredRPM = server.arg("value").toInt();
  server.sendHeader("Location", "/");
  server.send(303, "text/plain", "");
}

void handleSetDelay() {
  if (server.hasArg("value")) {
    unsigned long v = server.arg("value").toInt();
    if (v >= 1000 && v <= 10000000) actuatorDelayUs = v;
  }
  server.sendHeader("Location", "/");
  server.send(303, "text/plain", "");
}

void handleSetAngle() {
  if (server.hasArg("value")) {
    float v = server.arg("value").toFloat();

    if (v >= 0.0f && v <= 360.0f) {
      actuatorAngleDeg = v;

      if (measuredRPM > 0) {
        unsigned long revTimeUs = 60000000UL / measuredRPM;
        actuatorDelayUs = (unsigned long)((actuatorAngleDeg / 360.0f) * revTimeUs);
      }
    }
  }

  server.sendHeader("Location", "/");
  server.send(303, "text/plain", "");
}


void handleData() {
  String json = "{";
  json += "\"measuredRPM\":" + String(measuredRPM) + ",";
  json += "\"desiredRPM\":"  + String(desiredRPM) + ",";
  json += "\"delay\":"       + String(actuatorDelayUs) + ",";
  json += "\"angle\":"       + String(actuatorAngleDeg) + ",";
  json += "\"arm\":"         + String(armEnabled ? "true" : "false");
  json += "}";
  server.send(200, "application/json", json);
}

// =====================================================
// Setup
// =====================================================
void setup() {
  Serial.begin(115200);
  delay(200);

  pinMode(PIN_HALL, INPUT_PULLDOWN);
  attachInterrupt(digitalPinToInterrupt(PIN_HALL), ISR_Hall, RISING);

  fireTimer = timerBegin(0, 80, true);
  timerAttachInterrupt(fireTimer, &ISR_FireTimer, false);

  mcpwm_gpio_init(MCPWM_UNIT_0, MCPWM0A, PIN_SERVO);
  mcpwm_config_t pwm = {};
  pwm.frequency = 50;
  pwm.cmpr_a = 7.5;
  pwm.counter_mode = MCPWM_UP_COUNTER;
  pwm.duty_mode = MCPWM_DUTY_MODE_0;
  mcpwm_init(MCPWM_UNIT_0, MCPWM_TIMER_0, &pwm);

  mcpwm_set_duty_in_us(MCPWM_UNIT_0, MCPWM_TIMER_0, MCPWM_OPR_A, SERVO_HOME);

  WiFi.softAP(ssid, password);
  Serial.println(WiFi.softAPIP());

  server.on("/", handleRoot);
  server.on("/arm", handleArm);
  server.on("/setRPM", handleSetRPM);
  server.on("/setDelay", handleSetDelay);
  server.on("/setAngle", handleSetAngle);
  server.on("/data", handleData);
  server.begin();
}

// =====================================================
// Loop
// =====================================================
void loop() {
  server.handleClient();

  if (newHallPulse) {
    newHallPulse = false;
    if (deltaTime > 0) {
      measuredRPM = 60000000UL / deltaTime;
      updateActuatorDelay(); 
    }
  }

  if (servoFiredISR) {
    servoFiredISR = false;
    servoFired = true;
    servoFireTimestamp = micros();
  }

  if (servoFired && micros() - servoFireTimestamp > RETURN_DELAY_US) {
    servoFired = false;
    mcpwm_set_duty_in_us(MCPWM_UNIT_0, MCPWM_TIMER_0, MCPWM_OPR_A, SERVO_HOME);
  }
}

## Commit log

2026-01-22 added schematic + partslist
    [Partslist.xlsx, SchematicV1.fzz]
2026-01-27 Rotor/ReleaseMec/Hall+Electronic Box
    [ESP box.ipt, Flansch 3Ddruck.ipt, HoldingPin.ipt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]
2026-01-27 added camera settings picture
2026-01-28 doku stuff
    [Partslist.xlsx]
